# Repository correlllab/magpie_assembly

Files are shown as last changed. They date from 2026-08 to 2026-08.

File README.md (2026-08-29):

<div align="center">

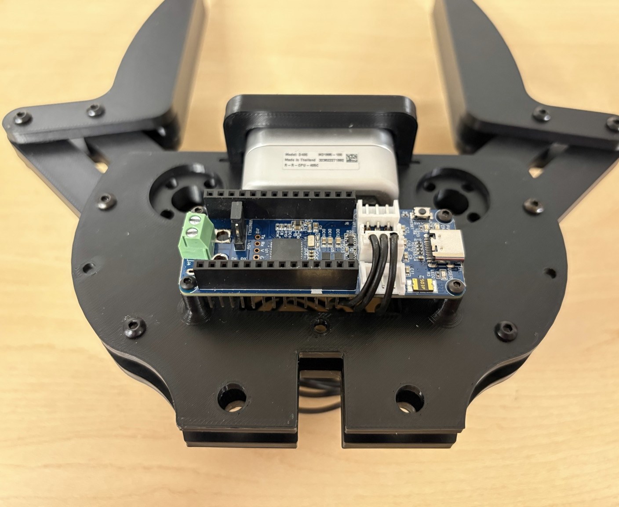
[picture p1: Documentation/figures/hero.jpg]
The assembled Magpie gripper V2, seen from above


# Magpie Gripper

**Design and manufacture of the MAGPIE hand — version 2**

A 3D-printed parallel-jaw gripper with a depth camera in its palm, built from
two smart servos and about $455 of off-the-shelf parts.







</div>

---

Two AX-12A servos drive a four-bar linkage — crank and rocker — that keeps the
fingers parallel through their whole travel, an OpenRB-150 board controls them,
and an Intel RealSense D405 looks out from the palm. Because the servos are
current-limited, the gripper can be told how hard to squeeze; because the camera
is between the fingers rather than on the wrist, it can still see the object at
the moment of contact.

This repository is the **hardware**: models, bill of materials, a photographed
step-by-step build, and the record of what changed from version 1. The software
that drives it lives in [correlllab/MAGPIE](https://github.com/correlllab/MAGPIE).

**Version 2 is a simplification.** Fewer parts, fewer fasteners, and less to get
wrong: the three-piece finger became one piece, the camera moved from slots to
holes so it lands in the same place every time, the controller's standoffs are
printed into the base plate, and the two-piece camera cover became one part that
snaps on. It weighs **390 g** on the bench scale, against 414 g for the hand in
the paper. [What changed, and why →](Documentation/MagpieDesignChanges.md)

|  |  |
| --- | --- |
| **Actuation** | 2 × Dynamixel AX-12A, four-bar linkage per finger |
| **Control** | OpenRB-150, one USB-C cable |
| **Sensing** | Intel RealSense D405 in the palm |
| **Mass** | ≈ 390 g ([weighed](Documentation/assembly_photos/IMG_5022.jpg)) |
| **Parts cost** | ≈ $455, of which the camera is $272 |
| **Printed** | 9 pieces, ≈ 140 cm³, PLA at 30 % gyroid infill |
| **CAD** | Onshape, [live document](https://cad.onshape.com/documents/ebf3bee4cb16cf8695a8fb0b/w/7cb77bbbbc0cfa118c533903/e/7df3b127506ca0a4fec0e6dc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) · STLs in [`CAD/`](CAD) |

## Build one

**1 · Print.** Everything in [`CAD/`](CAD), PLA, 30 % gyroid infill with 2 mm
borders and organic supports. The rocker and the crank are the parts that break,
so give them at least 50 % infill.

<div align="center">
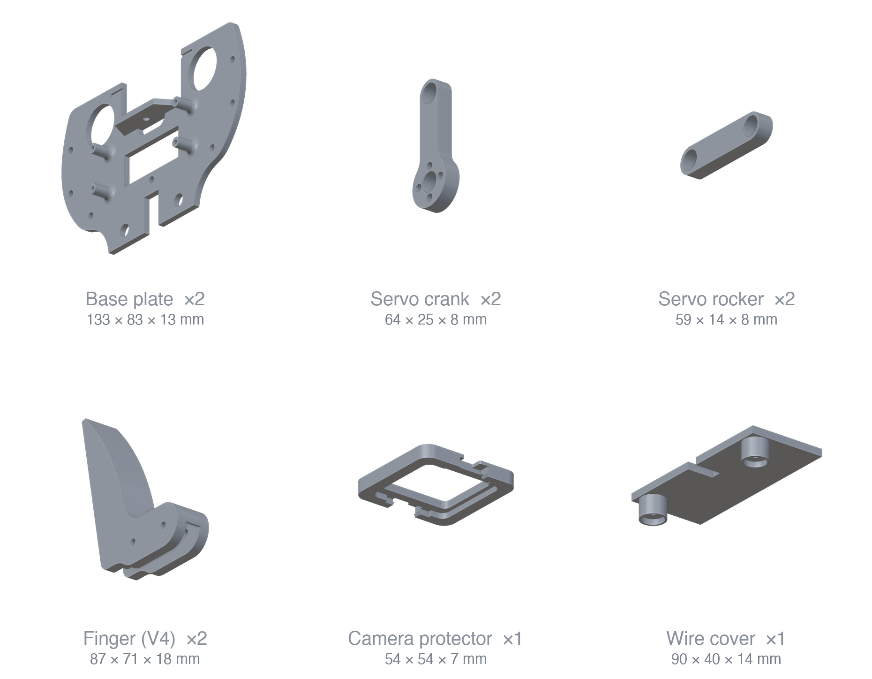
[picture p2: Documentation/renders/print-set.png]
The six printed parts of the V2 gripper, rendered at a common scale

</div>

| | Part | Qty | Size | File |
| --- | --- | ---: | --- | --- |
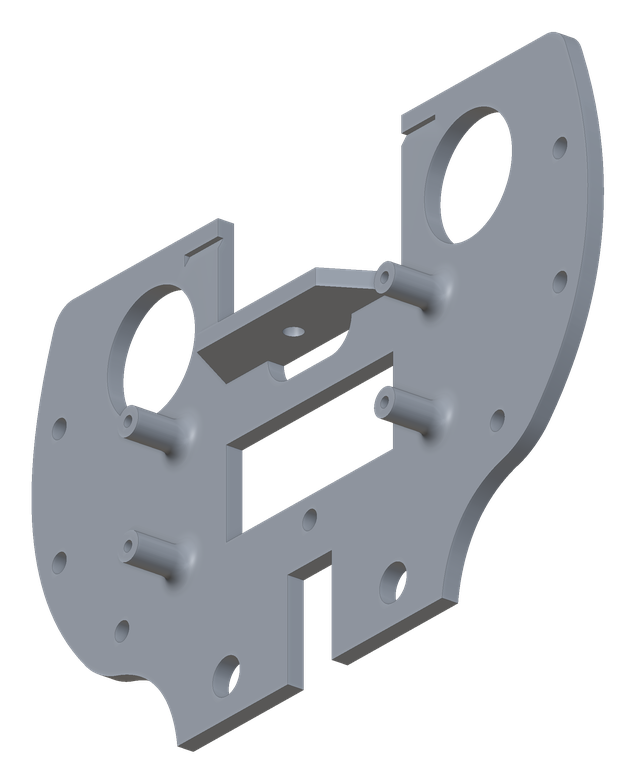
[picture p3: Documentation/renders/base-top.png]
|  | Base plate | 2 | 133 × 83 × 13 mm | [`Base Top.stl`](CAD/Base%20Top.stl), [`Base Bottom.stl`](CAD/Base%20Bottom.stl) |
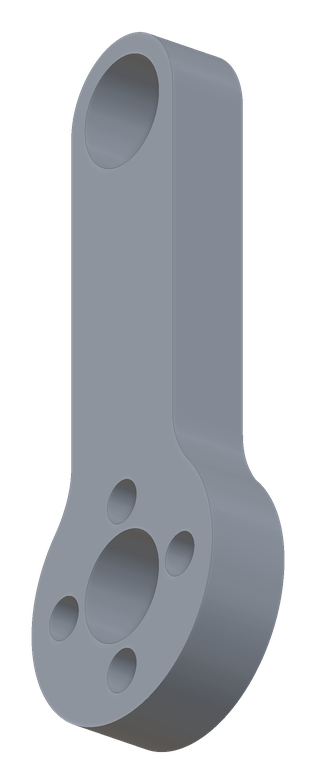
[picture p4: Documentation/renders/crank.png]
|  | Servo crank | 2 | 64 × 25 × 8 mm | [`Crank.stl`](CAD/Crank.stl) |
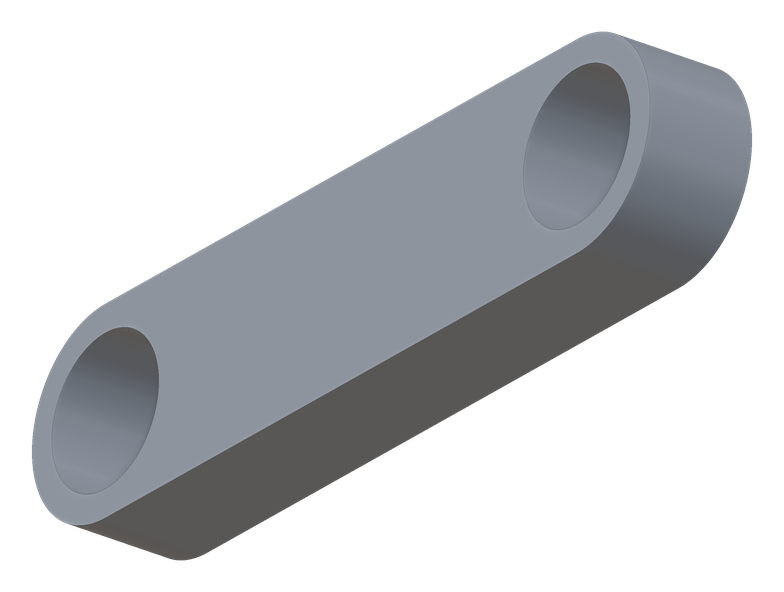
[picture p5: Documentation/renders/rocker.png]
|  | Servo rocker | 2 | 59 × 14 × 8 mm | [`Rocker.stl`](CAD/Rocker.stl) |
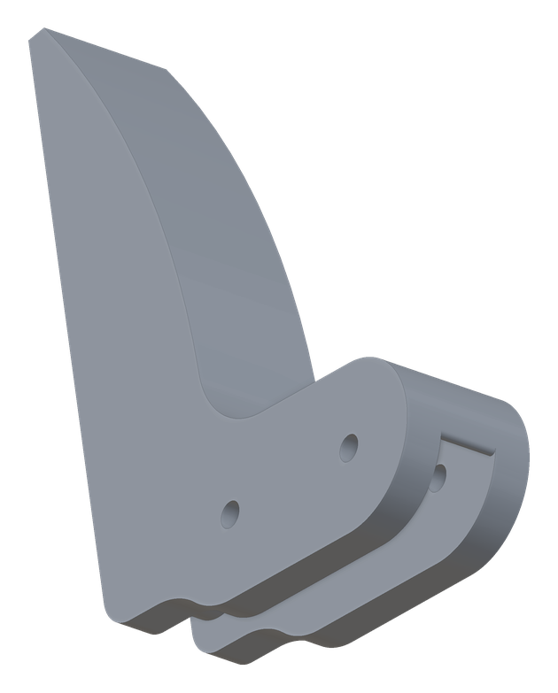
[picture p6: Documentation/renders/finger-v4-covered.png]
|  | Finger | 2 | 87 × 71 × 18 mm | [`Finger V4 - covered.stl`](CAD/Finger%20V4%20-%20covered.stl) |
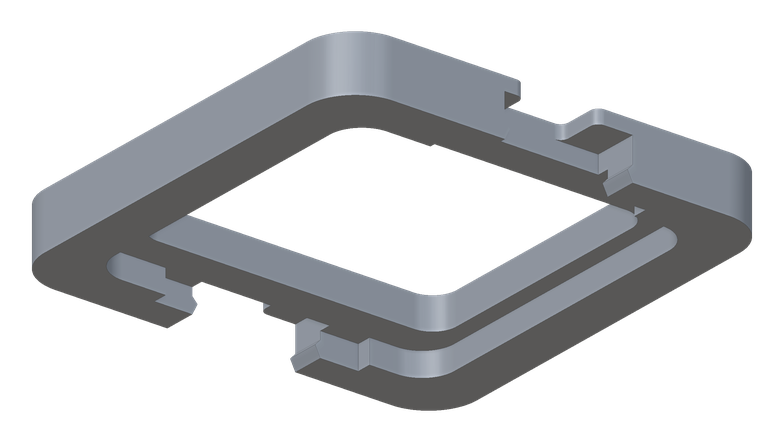
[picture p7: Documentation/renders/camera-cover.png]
|  | Camera protector | 1 | 54 × 54 × 7 mm | [`Camera Cover.stl`](CAD/Camera%20Cover.stl) |
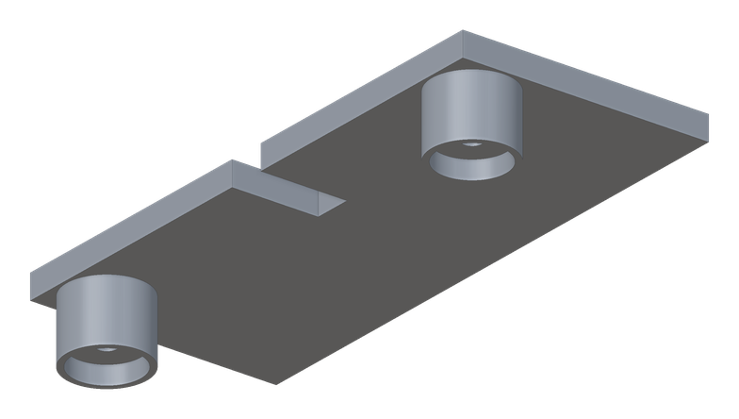
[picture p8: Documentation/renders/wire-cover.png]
|  | Wire cover | 1 | 90 × 40 × 14 mm | [`Wire Cover.stl`](CAD/Wire%20Cover.stl) |

> [!NOTE]
> `Base Top.stl` and `Base Bottom.stl` are currently **the same file, byte for
> byte** — it is the plate carrying the printed OpenRB-150 standoffs. If version 2
> really does use one plate twice, the BOM (which prices them separately) and the
> assembly guide (which says the plates are different sizes) should say so;
> otherwise the second export is missing.

**2 · Buy.** [The bill of materials](Documentation/BOM.md) lists both versions.
For V2: two AX-12A servos, an OpenRB-150, a RealSense D405, six 5 mm bearings,
M2/M3 hardware, and grip tape.

**3 · Assemble.** [The assembly guide](Documentation/assembly.md) — eleven steps,
photographed, from taping the fingers to setting the servo IDs. Also available as
[a PDF to print](Documentation/Magpie%20Assembly%20Guide.pdf).

## The fingers are the experiment

Grip is where a jaw gripper is won or lost, so the finger is the part that has
been through the most versions. All four are in [`CAD/`](CAD) and interchangeable:

<div align="center">
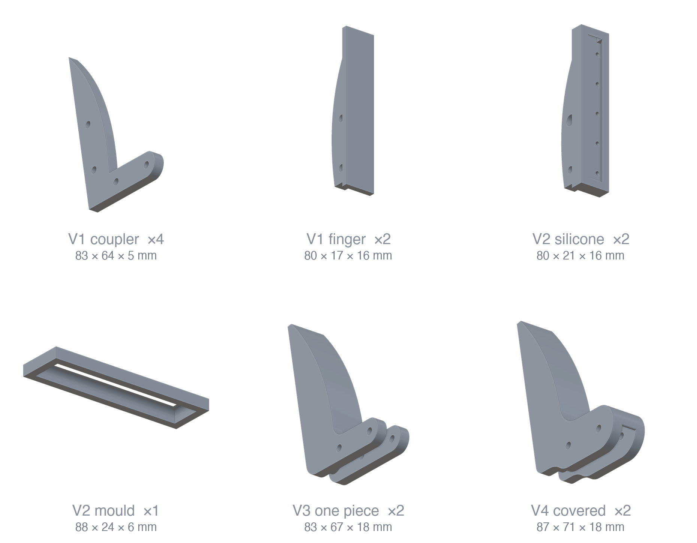
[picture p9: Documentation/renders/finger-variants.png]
The four finger designs rendered side by side

</div>

- **V1** — a separate coupler and finger, so the contact face could be printed in TPU.
- **V2** — a cast silicone finger, with the mould to make it.
- **V3** — finger and coupler as one part; simpler to print and assemble, and it needs grip tape to match the older grip.
- **V4** — V3 plus a cover that takes the play out of the joint and stiffens it.

## Driving it

Force control, the palm camera, grasp planning and the behaviour-tree/PDDL layer
are in **[correlllab/MAGPIE](https://github.com/correlllab/MAGPIE)** — a Python
package, no ROS. Once the gripper is wired and its servo IDs are set, that is
where to go next.

## What is in here

```
CAD/                      STL models — gripper mechanism and every finger variant
Documentation/
  assembly.md             the build, step by step, on GitHub
  Magpie Assembly Guide.pdf   the same guide, to print
  BOM.md                  bill of materials, V1 and V2
  MagpieDesignChanges.md  what changed from V1, and why
  figures/                the guide's figures
  assembly_photos/        every build photo, full resolution
  design_photos/          CAD comparisons, old against new
  renders/                part renders, generated from the STLs
  paper/                  the paper this hand comes from
tools/                    regenerate the renders and the figures
```

## License

MIT — see [LICENSE](LICENSE). The models, the bill of materials and the guide are
yours to print, modify and sell; the software that drives the gripper,
[correlllab/MAGPIE](https://github.com/correlllab/MAGPIE), is MIT too.

Built in the [Correll Lab](https://www.colorado.edu/lab/correll/) at the
University of Colorado Boulder.

## Citation

The hand this one descends from — its four-bar linkage, its force
characterisation and the manipulation pipeline built on it — is described in
[**A versatile robotic hand with 3D perception, force sensing for autonomous
manipulation**](https://arxiv.org/abs/2402.06018) (RSS 2024 Workshop on
Perception and Manipulation Challenges for Warehouse Automation, Daejeon, Korea).
A copy is kept here at
[`Documentation/paper/2402.06018-magpie.pdf`](Documentation/paper/2402.06018-magpie.pdf),
recompressed to keep a clone small — [arXiv](https://arxiv.org/abs/2402.06018) has
the original.

```bibtex
@inproceedings{correll2024versatile,
  title     = {A versatile robotic hand with {3D} perception, force sensing for
               autonomous manipulation},
  author    = {Correll, Nikolaus and Kriegman, Dylan and Otto, Stephen and
               Watson, James},
  booktitle = {RSS Workshop on Perception and Manipulation Challenges for
               Warehouse Automation},
  address   = {Daejeon, Korea},
  year      = {2024},
  eprint    = {2402.06018},
  archivePrefix = {arXiv},
  primaryClass  = {cs.RO},
  url       = {https://arxiv.org/abs/2402.06018}
}
```

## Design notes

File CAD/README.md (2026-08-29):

Updated: 8/19/2026

This directory contains the 3D models for the Magpie Gripper and its interchangeable fingers.

The original parametric modeling for this project was done in Onshape. To ensure compatibility for anyone looking to manufacture or modify the design, the files here have been exported into standard universal formats.

File Format:'.stl': 

Printing Guidelines:
Print using PLA with 30% gyroid infill or 100% infill

Original CAD files are contained within this folder. The CAD assembly is located in this [Onshape](https://cad.onshape.com/documents/ebf3bee4cb16cf8695a8fb0b/w/7cb77bbbbc0cfa118c533903/e/7df3b127506ca0a4fec0e6dc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) document

Renders of every part, generated from these files, are in
[`../Documentation/renders/`](../Documentation/renders); the print set and the
finger variants are laid out side by side there at a common scale.

Note: `Base Top.stl` and `Base Bottom.stl` are currently identical files — the
plate with the printed OpenRB-150 standoffs. See the note in the
[top-level README](../README.md#build-one).

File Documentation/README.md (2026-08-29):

# Documentation

Everything needed to source the parts and put a Magpie gripper together.

| | |
| --- | --- |
| [**assembly.md**](assembly.md) | The step-by-step build, with photographs. Read this on GitHub. |
| [**Magpie Assembly Guide.pdf**](Magpie%20Assembly%20Guide.pdf) | The same guide, formatted to print and take to the bench. |
| [**BOM.md**](BOM.md) | Bill of materials for both versions — hardware, electronics, and grams of filament, with prices. |
| [**MagpieDesignChanges.md**](MagpieDesignChanges.md) | What changed between version 1 and version 2, and the reasoning behind each change. |
| [`figures/`](figures) | The figures used by the assembly guide, cut out of the PDF. |
| [`assembly_photos/`](assembly_photos) | Every photograph taken during the build, full resolution — including the ones the guide did not use. |
| [`design_photos/`](design_photos) | CAD screenshots comparing the old design with the new one. |
| [`renders/`](renders) | Renders of each printed part, generated from the STLs by [`tools/render_stl.py`](../tools/render_stl.py). |
| [`paper/`](paper) | The paper the original hand was published in. |

**If you are building from scratch, read the BOM first** and make sure every item
is on the bench before you start — the guide assumes it.

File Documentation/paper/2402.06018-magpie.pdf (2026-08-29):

# A versatile robotic hand with 3D perception, force sensing for autonomous manipulation

Nikolaus Correll, Dylan Kriegman, Stephen Otto and James Watson Department of Computer Science, University of Colorado Boulder, Boulder, Colorado 80309–0430 Email: ncorrell@colorado.edu

Abstract—We describe a force-controlled robotic gripper with built-in tactile and 3D perception. We also describe a complete autonomous manipulation pipeline consisting of object detection, segmentation, point cloud processing, force-controlled manipulation, and symbolic (re)-planning. The design emphasizes versatility in terms of applications, manufacturability, use of commercial off-the-shelf parts, and open-source software. We validate the design by characterizing force control (achieving up to 32N, controllable in steps of 0.08N), force measurement, and two manipulation demonstrations: assembly of the Siemens gear assembly problem, and a sensor-based stacking task requiring replanning. These demonstrate robust execution of long sequences of sensor-based manipulation tasks, which makes the resulting platform a solid foundation for researchers in task-andmotion planning, educators, and quick prototyping of household, industrial and warehouse automation tasks.

I. INTRODUCTION

Autonomous manipulation remains a challenge in digitizing and automating value streams from manufacturing to recycling. These tasks include picking, placing, assembly/disassembly, and packing. They involve a large variety of compliance, for example when tightening a metal nut vs. grasping a delicate raspberry. Often, tasks of varying dexterity and compliance need to be combined, requiring a highly versatile hardware and software system. Implementing such a system is difficult. Commercially available grippers have limited capabilities, particularly the absence of torque control, and therefore lack of active compliance [1]. Integration with vision systems is not straightforward; wrist-mounted, tabletop, and palm-mounted cameras can be occluded at different times during operation. Finally, software frameworks such as ROS take considerable effort to commission and maintain, which is often unnecessary in particular when the goal is to investigate only one aspect of a manipulation pipeline such as vision or high-level reasoning. In this paper, we present a lightweight manipulation architecture geared at researchers, educators, and hobbyists, that is able to perform a wide variety of multi-step manipulation tasks, while being simple to manufacture and affordable (Figure 1).
The “gold standard” in manipulation is the human hand, which is able to perform an extensive range of tasks, including tool usage and in-hand manipulation [13]. Prominent designs in this category are the “ShadowHand” that is able to manipulate a Rubik’s cube [2], the RBO hand [4], and the Pisa/IIT hand [7]. These three examples also span a large spectrum of degrees of freedom from 24 (ShadowHand) to

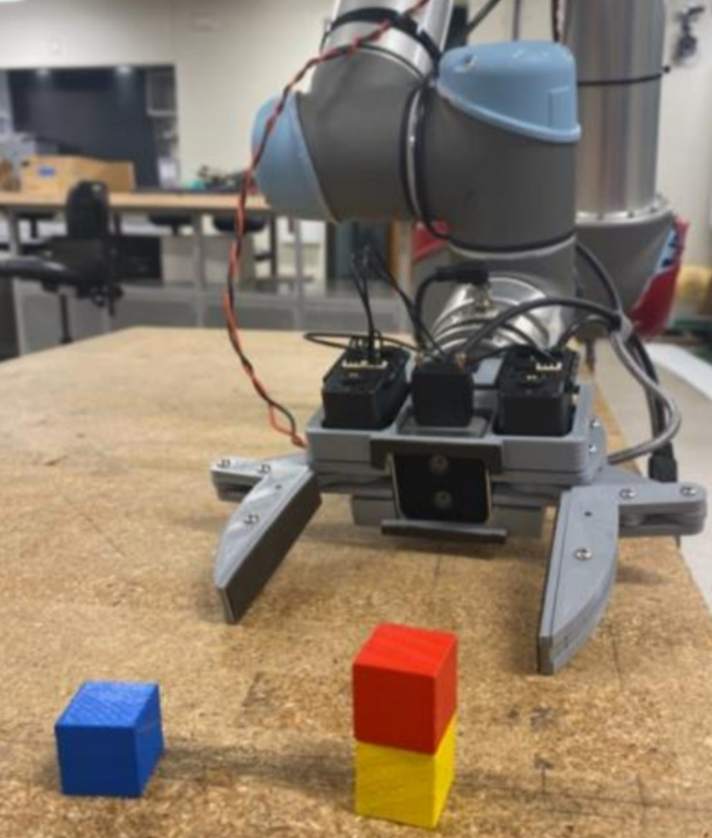
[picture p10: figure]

Fig. 1. All-in-one manipulation architecture that emphasizes manufacturability, active compliance, robust execution, and versatility. A light-weight software architecture combines object detection, segmentation, point cloud processing, with planning, inference and execution, creating a platform for research in task-and-motion planning for complex manipulation problems.
the underactuated Pisa hand which has 19 joints driven by only a single actuator. Benchmarking an end-effector design is a challenging problem and subject to research. It is difficult to disentangle grasp planning from perception [3], robot arm from end-effector performance [19], and versatility from specialization, e.g. cloth manipulation [16] or warehouse picking [10].
One way to evaluate the capability of a hand design is to subject it to a wide variety of household tasks [22] that overlap with upper-limb prosthetic applications. In such a test, underactuated designs such as the Pisa hand [5] and a 100-year old claw design that has only a single actuated finger
[20] have outperformed all other designs in [22]. Although the Pisa hand’s compliance is advantageous when operating scissors, e.g., a simple mechanical design is intriguing due to its manufacturability, robustness, and simpler control [14] while still being highly versatile.
Although versatility is not important in conventional automation using highly specialized end-effectors such as during warehouse picking or assembly of the same part, versatility

# arXiv:2402.06018v1 [cs.RO] 8 Feb 2024

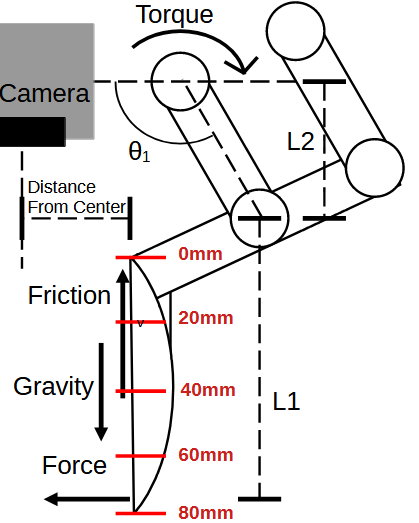
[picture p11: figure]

Fig. 2. Torque Diagram to Calculate Estimated Force on the Object.
will become critical for recovering from errors or when a task not only requires picking, but precise placement, e.g. during packing.
In previous work, we have designed an industrial-grade robotic gripper following these design principles that integrated 3D perception, force control and computation [12] to pick up items as small as a washer and as large as a commercial toner cartridge. The system is gentle enough to handle a strawberry, and strong enough to tighten a nut. In this paper, we describe a design with much-improved manufacturability by relying on commercial, off-the-shelf motors and cameras, forgoing costly custom integration of computation and cabling. Although sacrificing ruggedness and stand-alone capability, this design can be manufactured at a fraction of the cost (around $460 in parts including camera), and less than half of the weight (414g), allowing operation on a wide range of robotic arms, while requiring only a 3D printer and off-theshelf parts such as stand-offs and bearings.
Based on experience with a wide range of robotic competitions ranging from warehouse picking [10], household automation [20], robotic assembly [24] and mobile manipulation [21], we have developed a perception and planning pipeline that combines recent advances in low-cost 3D perception with deep learning for instance-segmentation, and conventional planning. Here, the emphasis of our architecture is to robustly deal with sequencing hundreds of behaviors based on visual and tactile cues. The software stack is released under the MIT License¹ .

II. DESIGN

A. Hardware
Our design is driven by the requirement to perform assembly tasks involving parts as small as M3 nuts driven by the robotic assembly domain [24] and household tasks as in [22]. Trading strength and size for manufacturability and cost, we designed the system to pick up 88% of the items in the YCB benchmark [6], excluding the hammer, the power drill, the pan, and other large objects. With this, we were able to specify the gripper aperture and motor strength, assuming a conservative friction coefficient of µ = 0.4 and a safety factor of 1.5.

1https://github.com/correlllab/MAGPIE

The 4-bar linkage design (Figure 2) provides a maximal field of view for the palm-mounted camera (Intel RealSense D405), providing a maximum aperture of w = 106.24mm. All pieces have been 3D printed using PLA. Although PLA printed parts have lesser stiffness than Delrin or ABS sheets, laser cutters are not available to most educators and hobbyists. All links use M5 bearings that are press-fitted into openings in the PLA material and M3 screws as the axis. We found using bearings to greatly reduce friction, while press-fitting reduces play and thereby increases the accuracy of the mechanism. The AX-12 servo motors (Robotis, Korea) have a stalltorque τ of 1.5Nm. The AX-12’s digital interface allows setting and measuring the actual motor torque via current control, thereby enabling compliant control and detecting objects within the gripper. Independently controlling the fingers helps to prevent the gripper to get stuck when one of its fingers is impeded, e.g. when picking items from clutter, as well as grasping objects off center [12].
The Intel RealSense camera has an operational range from 7cm to 50cm with a field of view of 87o × 58o

and a resolution
of 1280 × 720. It can detect objects as small as 0.1mm, making it ideal for in-hand perception applications. The camera is mounted in the palm [12], allowing the hand to see an object until contact is made, minimizing distortion and occlusion, when compared to wrist- and table-mounted cameras. Figure 6 (center), shows a snapshot through the camera, with only minimal occlusion by the fingers.
B. Software
Our grasping pipeline follows the outline described in [11]: objects are detected from RGB camera images using pixelwise segmentation based on Yolo v5²
. Segmentation masks
are then used to isolate 3D point cloud information from individual objects. We determine the orientation of the point cloud using principal component analysis (PCA), compute a grasp pose based on the object’s bounding box, and use an inverse kinematics solver from Peter Corke’s robotic toolbox
[9] to move the robotic arm to the desired pose. Together, these components create a robust pipeline in which individual elements can be replaced for research or education. All of the behaviors are embedded into Behavior Tree (BT) [8] nodes that allow for robust engineering of multi-state robot controllers.
In order to be able to manage long task sequences comprising hundreds of steps, e.g. as required during assembly of complex mechatronics [24], our planner automatically generates BTs from a high-level task description of the scene in PDDL 2.1 [15], which can be efficiently solved by the AI planning framework FastDownward [17] that we interface via py2PDDL [18]. Here, the planning problem is populated from the Yolo v5 object recognition pipeline after every step and the plan is recomputed to catch potential execution failures. Here, spatial relationships between objects (e.g. “on top”) are hard-coded. This framework is illustrated in Figure 6, showing

2https://github.com/ultralytics/yolov5

Bill of Materials

ID | Item | Quantity | Cost
1 | Top Base(PLA) | 1 | $ 1.51
2 | Top Base Cover(PLA) | 1 | $ 2.05
3 | Bottom Base(PLA) | 1 | $ 1.17
4 | Bottom Base Cover(PLA) | 1 | $ 1.15
5 | Servo Crank(PLA) | 2 | $ 0.47
6 | Servo Coupler(PLA) | 4 | $ 1.56
7 | Servo Rocker(PLA) | 2 | $ 0.28
8 | Finger | 2 | $ 0.86
9 | OpenRB-150 board | 1 | $ 24.90
10 | Intel® RealSense™ D405 | 1 | $ 272.00
11 | AX-12A Servo Motor | 2 | $ 99.80
12 | 3M 6mm standoff | 4 | $ 9.99
13 | 3M 8mm standoff | 8 | $ 9.99
14 | 2.5M 10mm standoff | 4 | $ 9.99
15 | Electrical Wire | 2 | $ 0.45
16 | 3M Nuts and Bolts | 32 | $ 12.49
17 | 2M Nuts and Bolts | 8 | $ 9.99
18 | 5M bearings | 8 | $ 9.99
| | Total | $458.63

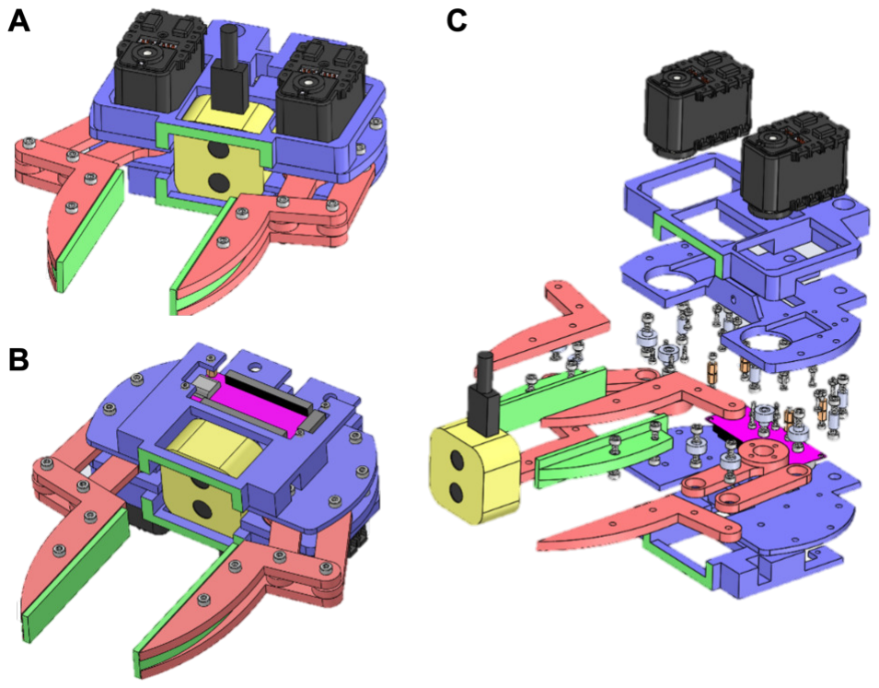
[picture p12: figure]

Fig. 3. | Left: CAD Drawings of the gripper from the top (A), bottom (B), and exploded view (C). Each motor independently actuates a finger, providing
independent torque-based control. The camera is integrated into the palm. Right: Bill of Materials with approximated cost. PLA with a cost of $0.05 per cm2 .

an example of successful task completion despite errors during
execution by continuous replanning.

III. EVALUATION
a) Hardware: In order to test the torque-controlling ability of the servo, we measure the force at the finger as a function of the dimensionless Dynamixel settings in the range of 0–1023. A force gauge (Shimpo FGV-10XY) was locked into a vice to hold it securely for all measurements. The force gauge gives an error of ±.2%. The force increases linearly (R² = .995, y = 0.0316x−3.0194) from 0 to 9N at “400” and then increases to 32N following a second-degree polynomial function (R² = .999). In the linear regime, we are able to change force in increments of 0.08N.
We also demonstrate the gripper’s ability to sense force/torque. Figure 4 shows the force profile for the right (‘Motor 1’) and the left (‘Motor 2’) finger vs. gripper aperture as the gripper closes on the mustard container from the YCB dataset. The container was placed off-center, with the right motor making contact first. Instead of moving the mustard, the finger remains in position until the second finger makes contact. We observe minimal torques while moving the finger, with Motor 1 having more friction than Motor 2 due to variations in manufacturing.
To demonstrate the precision and accuracy of the design, we perform a robotic assembly task with tight tolerances (< 0.5mm). Snapshots of the task are shown in Figure 5. Precision and accuracy of grasping the elements from a known position on the kitting mat (modeling the industrial assembly challenge requirements from [24]) is sufficient to reliably assemble all parts into a functioning mechanical system. The open-loop assembly task succeeded 8 out of 10 trials; with one failure each due to an angular misalignment of the small peg and the large gear becoming jammed on the large peg. These results motivate a sensor-based re-planning approach such as described in [25].
b) Software: We evaluated the system using a towerassembly task using three colored, wooden cubes from [6].

Figure 6 shows snapshots of the experiment, a view of the camera image, the resulting labeled 3D objects, and the corresponding PDDL domain. FastDownward automatically generates a plan, which our system translates into a behavior tree to execute the necessary steps. Running this loop once corresponds to the classical sense-plan-act approach. Updating the PDDL domain and replanning accordingly allows for more sophisticated behavior, including reacting to changes in the environment or recovering from errors in execution. We ran a single step, moving one block from one tower to another, 50 times. Of the 42 successful attempts, 30 were completed at the first trial, 6 required two trials, and 3, 2, and 1 experiments required 3, 4, and 6 trials. The other 8 failed in a way that could not be recovered with this simple program, for example when a block was moved out of the field of view of the hand.

IV. DISCUSSION AND CONCLUSION
The proposed design exceeds the capabilities of [12] in terms of perception and in the dimensions of objects that can be picked up. Yet, 3D-printed PLA plastics cannot reach the level of stiffness and accuracy that a sheet-metal-based design can, which is a disadvantage when grasping very small pieces, such as an M3 screw that requires exact alignment of the fingers.
The current design requires three external cables that need to be routed along a robotic arm: a USB 3.1 connection for the camera, a USB 2.0 connection for the motor control board, and a power cable that can provide up to 3A at 12V (36W). All of these could be met by a single USB-C PD connection, in particular when 5V to 12V step-up circuits with sufficient power are available.
The emphasis on the software pipeline is to demonstrate modularity (via the BT framework and STRIPS planner), rather than performance on specific subtasks. Indeed, components such as object detection could be easily tuned to achieve 100% one-shot success rate in the tower assembly task. Failure has been instructive as it will be pervasive in autonomous settings, and remain a problem if it occurs with a non-zero

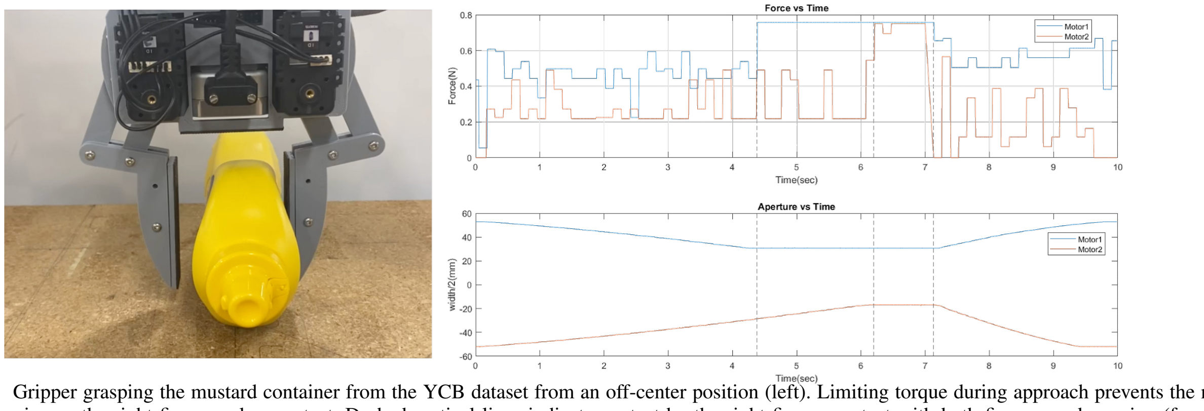
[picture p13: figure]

Fig. 4. Gripper grasping the mustard container from the YCB dataset from an off-center position (left). Limiting torque during approach prevents the mustard from moving as the right finger makes contact. Dashed vertical lines indicate contact by the right finger, contact with both fingers, and opening (from left to right).

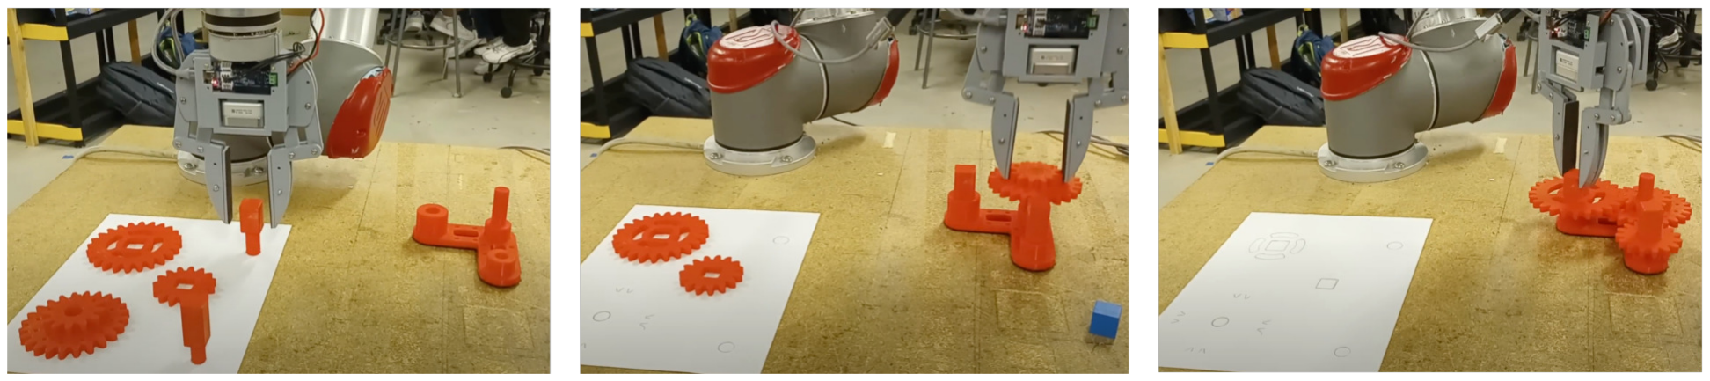
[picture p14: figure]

Fig. 5. Demonstration of accuracy and precision by reliably assembling the “Siemens gear assembly problem” [23] with sub-millimeter accuracy requirements.

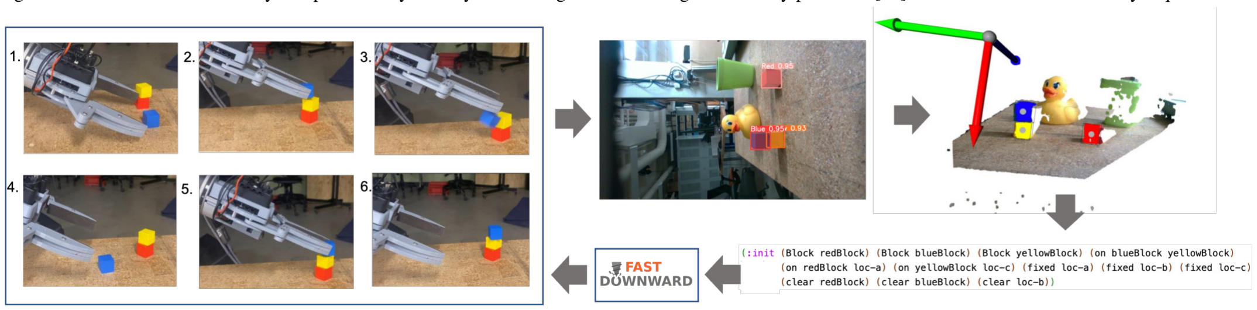
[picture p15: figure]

Fig. 6. Snapshots from a tower construction task that is solved by continuous replanning. The robot accidentally hits the tower (1) while placing the blue block (2), which fails as the tower has moved (3), the robot re-analyzes the scene (4), and places the blue block (5). Point cloud and image data are used for object identification and segmentation, resulting into a labeled scene that gets parsed into a PDDL 2.1 problem description and solved by FastDownward. The plan is repeated until the problem is solved.

probability. Here, we are particularly interested in reasoning
under uncertainty and generating high-level plans for recovery
from error using semantic domain knowledge. For example, when an object moves outside of the robot’s field of view, the robot could search for it and move objects out of the way if it has to. We plan to further explore this in the future by interfacing PDDL descriptions with large language models to (1) generate problem descriptions from image/3D data,
(2) generate PDDL descriptions from natural language, and
(3) use domain knowledge to increase the robot’s reasoning abilities. Finally, we are interested in building upon this design to perform better on heavy items by adding a thumb, operating tools such as a power-drill by adding an additional degree of freedom to one finger, and fast picking by adding a suction

cup.

ACKNOWLEDGEMENTS
This work has been supported by a grant by the National Science Foundation “USDA-NIFA NRI INT: Autonomous Restoration and Revegetation of Degraded Ecosystems”.

REFERENCES
[1] A. Albu-Schaffer, O. Eiberger, M. Grebenstein, S. Haddadin, C. Ott, T. Wimbock, S. Wolf, and G. Hirzinger. Soft robotics. IEEE Robotics & Automation Magazine, 15(3):20–30, 2008.
[2] O. M. Andrychowicz, B. Baker, M. Chociej, R. Jozefowicz, B. McGrew, J. Pachocki, A. Petron, M. Plappert,
G. Powell, A. Ray, et al. Learning dexterous in-hand manipulation. The International Journal of Robotics Research, 39(1):3–20, 2020.
[3] Y. Bekiroglu, N. Marturi, M. A. Roa, K. J. M. Adjigble,
T. Pardi, C. Grimm, R. Balasubramanian, K. Hang, and
R. Stolkin. Benchmarking protocol for grasp planning algorithms. IEEE Robotics and Automation Letters, 5 (2):315–322, 2019.
[4] A. Bhatt, A. Sieler, S. Puhlmann, and O. Brock. Surprisingly robust in-hand manipulation: An empirical study. arXiv preprint arXiv:2201.11503, 2022.
[5] M. Bonilla, C. D. Santina, A. Rocchi, E. Luberto, G. Santaera, E. Farnioli, C. Piazza, F. Bonomo, A. Brando,
A. Raugi, et al. Advanced grasping with the pisa/iit softhand. In Robotic Grasping and Manipulation: First Robotic Grasping and Manipulation Challenge, RGMC 2016, Held in Conjunction with IROS 2016, Daejeon, South Korea, October 10–12, 2016, Revised Papers 1, pages 19–38. Springer, 2018.
[6] B. Calli, A. Singh, J. Bruce, A. Walsman, K. Konolige,
S. Srinivasa, P. Abbeel, and A. M. Dollar. Yale-cmuberkeley dataset for robotic manipulation research. The International Journal of Robotics Research, 36(3):261– 268, 2017.
[7] M. G. Catalano, G. Grioli, E. Farnioli, A. Serio, C. Piazza, and A. Bicchi. Adaptive synergies for the design and control of the pisa/iit softhand. The International Journal of Robotics Research, 33(5):768–782, 2014.
[8] M. Colledanchise and P. Ogren. ¨ | Behavior trees in
robotics and AI: An introduction. CRC Press, 2018.
[9] P. Corke and J. Haviland. Not your grandmother’s toolbox–the robotics toolbox reinvented for python. In 2021 IEEE International Conference on Robotics and Automation (ICRA), pages 11357–11363. IEEE, 2021.
[10] N. Correll, K. E. Bekris, D. Berenson, O. Brock,
A. Causo, K. Hauser, K. Okada, A. Rodriguez, J. M. Romano, and P. R. Wurman. Analysis and observations from the first amazon picking challenge. IEEE Transactions on Automation Science and Engineering, 15(1): 172–188, 2016.
[11] N. Correll, B. Hayes, C. Heckman, and A. Roncone. Introduction to Autonomous Robots: Mechanisms, Sensors, Actuators, and Algorithms. Mit Press, 2022.
[12] N. J. Correll, A. K. Miller, and B. Romero. Systems, devices, components, and methods for a compact robotic gripper with palm-mounted sensing, grasping, and computing devices and components, Oct. 19 2021. US Patent 11,148,295.
[13] R. Coulson, C. Li, C. Majidi, and N. S. Pollard. The elliott and connolly benchmark: A test for evaluating the in-hand dexterity of robot hands. In 2020 IEEE-RAS 20th International Conference on Humanoid Robots (Humanoids), pages 238–245. IEEE, 2021.
[14] R. S. Fearing. Simplified grasping and manipulation with dextrous robot hands. IEEE Journal on Robotics and Automation, 2(4):188–195, 1986.
[15] M. Fox and D. Long. Pddl2.1: An extension to pddl for expressing temporal planning domains. Journal of artificial intelligence research, 20:61–124, 2003.
[16] I. Garcia-Camacho, M. Lippi, M. C. Welle, H. Yin,
R. Antonova, A. Varava, J. Borras, C. Torras, A. Marino,
G. Alenya, et al. Benchmarking bimanual cloth manipulation. IEEE Robotics and Automation Letters, 5(2): 1111–1118, 2020.
[17] M. Helmert. The fast downward planning system. Journal of Artificial Intelligence Research, 26:191–246, 2006.
[18] R. Karem. | py2pddl. | https://github.com/remykarem/
py2pddl, (https://github.com/remykarem/py2pddl) 2022.
[19] A. S. Morgan, K. Hang, W. G. Bircher, F. M. Alladkani,
A. Gandhi, B. Calli, and A. M. Dollar. Benchmarking cluttered robot pick-and-place manipulation with the box and blocks test. IEEE Robotics and Automation Letters, 5(2):454–461, 2019.
[20] R. Patel, J. Segil, and N. Correll. Manipulation using the “utah” prosthetic hand: The role of stiffness in manipulation. In Robotic Grasping and Manipulation: First Robotic Grasping and Manipulation Challenge, RGMC 2016, Held in Conjunction with IROS 2016, Daejeon, South Korea, October 10–12, 2016, Revised Papers 1, pages 107–116. Springer, 2018.
[21] M. A. Roa, M. R. Dogar, J. Pages, C. Vivas,
A. Morales, N. Correll, M. Gorner, J. Rosell, S. Foix,
R. Memmesheimer, et al. Mobile manipulation hackathon: Moving into real world applications. IEEE Robotics & Automation Magazine, 28(2):112–124, 2021.
[22] Y. Sun, J. Falco, N. Cheng, H. R. Choi, E. D. Engeberg,
N. Pollard, M. Roa, and Z. Xia. Robotic grasping and manipulation competition: task pool. In Robotic Grasping and Manipulation: First Robotic Grasping and Manipulation Challenge, RGMC 2016, Held in Conjunction with IROS 2016, Daejeon, South Korea, October 10– 12, 2016, Revised Papers 1, pages 1–18. Springer, 2018.
[23] M. Vecerik, O. Sushkov, D. Barker, T. Rothorl, T. Hester, ¨ and J. Scholz. A practical approach to insertion with variable socket position using deep reinforcement learning. In 2019 international conference on robotics and automation (ICRA), pages 754–760. IEEE, 2019.
[24] F. Von Drigalski, C. Schlette, M. Rudorfer, N. Correll,
J. C. Triyonoputro, W. Wan, T. Tsuji, and T. Watanabe. Robots assembling machines: learning from the world robot summit 2018 assembly challenge. Advanced Robotics, 34(7-8):408–421, 2020.
[25] J. Watson, A. Miller, and N. Correll. Autonomous industrial assembly using force, torque, and rgb-d sensing. Advanced Robotics, 34(7-8):546–559, 2020.

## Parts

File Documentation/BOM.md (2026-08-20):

# Magpie Gripper Bill of Materials (BOM)

Note: All parts printed out of PLA are under the assumption that filament costs $0.05 per cm<sup>2

## Version 1

Note: All parts printed out of PLA have 15% crosshatch infill with 2mm borders and organic supports.

| ID | Item | Quantity | Cost (Approx.)
|---|---|---|---|
|1|Top Base (PLA)|1|$1.51|
|2|Top Base Cover (PLA)|1|$2.05|
|3|Bottom Base (PLA)|1|$1.17|
|4|Bottom Base Cover (PLA)|1|$1.15|
|5|Servo Crank (PLA)|2|$0.47|
|6|Servo Coupler (PLA)|4|$1.56|
|7|Servo Rocker (PLA)|2|$0.28|
|8|Finger (PLA)|2|$0.86|
|9|OpenRB-150 board|1|$24.90|
|10|Intel :registered: RealSense :tm: D405|1|$272.00|
|11|AX-12A Servo Motor|2|$99.80|
|12|3M 6mm standoff|4|$9.99|
|13|3M 8mm standoff|8|$9.99|
|14|2.5M 10mm standoff|4|$9.99|
|15|Electrical Wire|2|$0.45|
|16|3M Nuts and Bolts|32|$12.49|
|17|2M Nuts and Bolts|8|$9.99|
|18|5M bearings|8|$9.99|
| | |Total|$468.64|

## Version 2 (New)

Note: All parts printed out of PLA have 30% gyroid infill with 2mm borders and organic supports

| ID | Item | Quantity | Cost (Approx.) | 
|---|---|---|---|
|1|Top Base (PLA)|1|$1.01|
|2|Bottom Base (PLA)|1|$1.20|
|3|Servo Crank (PLA)|2|$0.52|
|4|Servo Rocker (PLA)|2|$0.38|
|5|Finger (PLA)|2|$2.20|
|6|Camera Protector (PLA)|1|$0.36|
|7|OpenRB-150 board|1|$24.90|
|8|Intel :registered: RealSense :tm: D405|1|$272.00|
|9|AX-12A Servo Motor|2|$99.80|
|10|3M 6mm standoff|4|$9.99|
|11|3M 8mm standoff|4|$9.99|
|12|Electrical Wire|2|$0.45|
|13|3M Nuts and Bolts|16|$12.49|
|14|2M Nuts and Bolts|20|$9.99|
|15|5M bearings|6|$9.99|
| | |Total|$455.28|

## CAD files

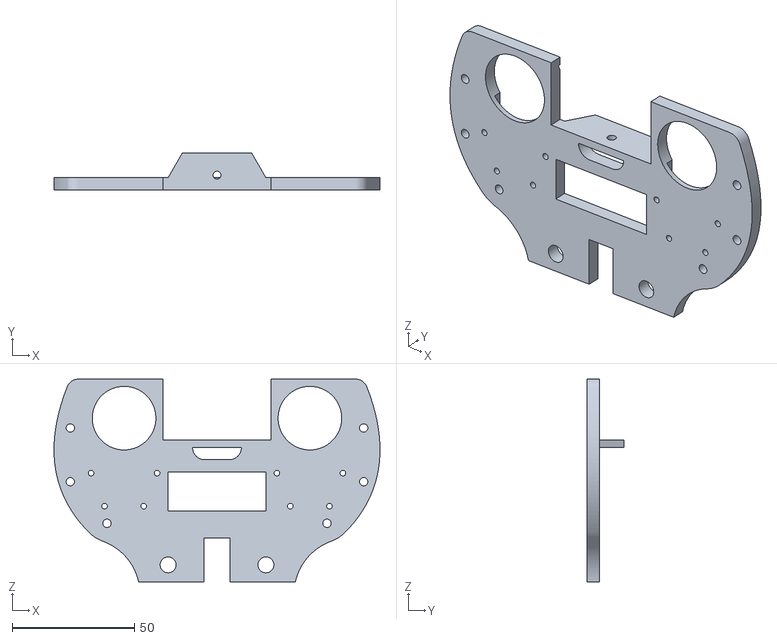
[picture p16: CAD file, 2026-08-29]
CAD/Top Base.stl
133.3 x 15.0 x 83.0

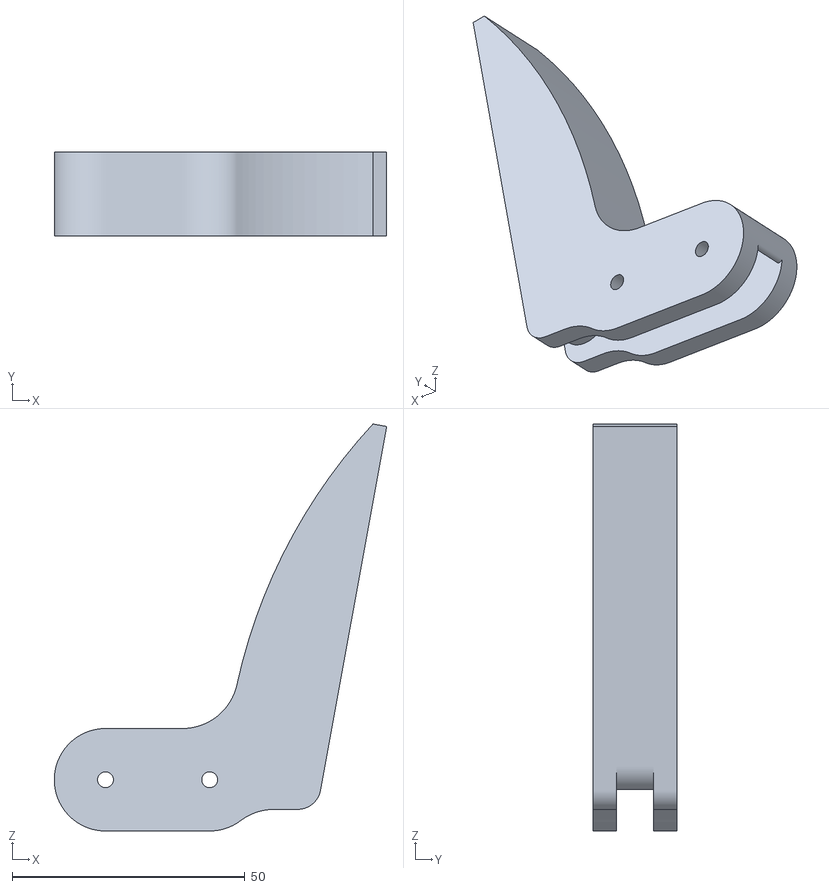
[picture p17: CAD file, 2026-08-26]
CAD/Finger V4 - covered.stl
71.4 x 18.0 x 87.4

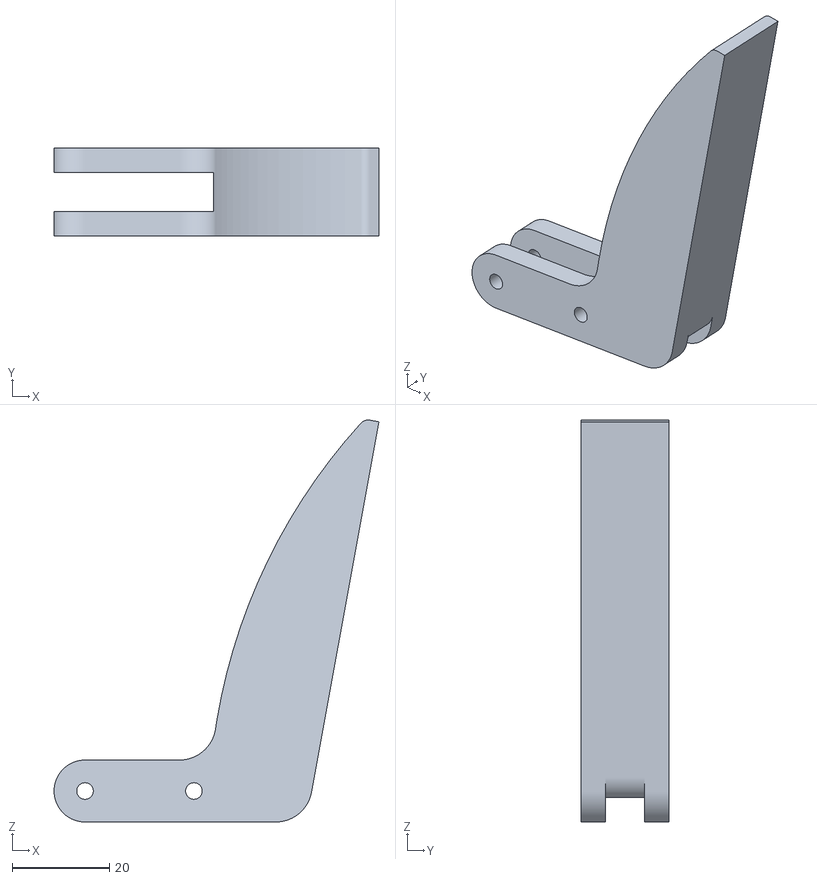
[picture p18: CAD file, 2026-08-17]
CAD/Finger V3 - Finger+Coupler.stl
66.7 x 18.0 x 82.6

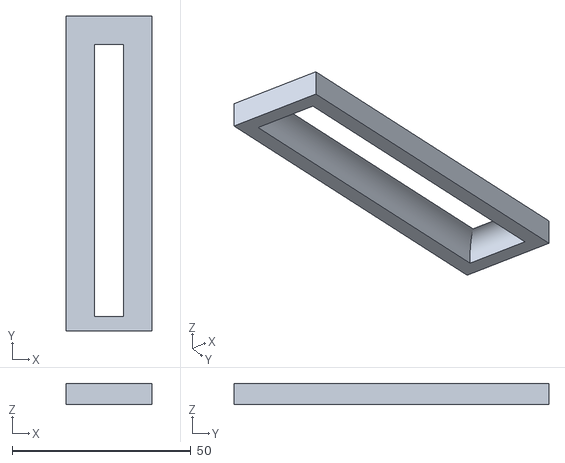
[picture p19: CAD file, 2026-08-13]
CAD/Finger V2 - Silicone Finger Mold.stl
24.2 x 88.2 x 6.00

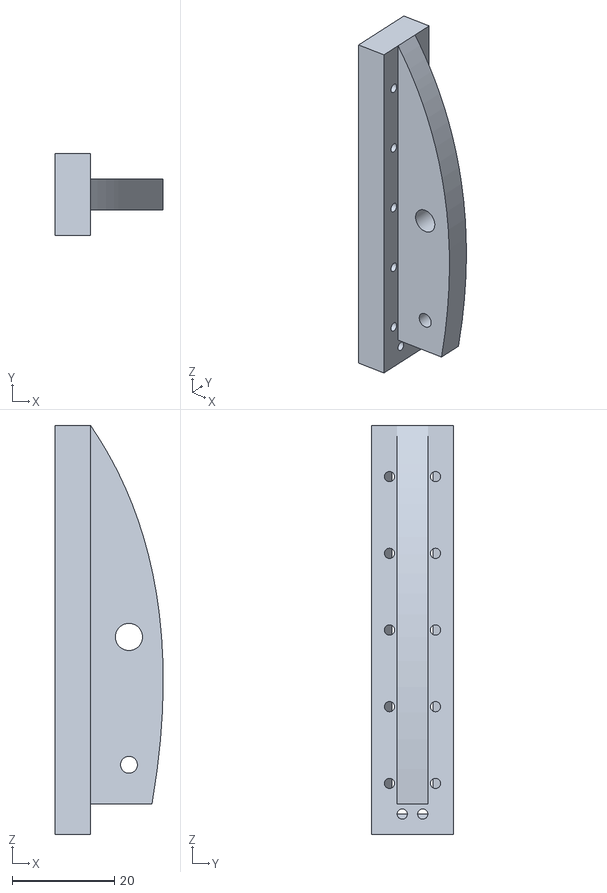
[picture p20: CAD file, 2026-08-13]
CAD/Finger V2 - Silicone Finger.stl
21.2 x 16.0 x 80.0

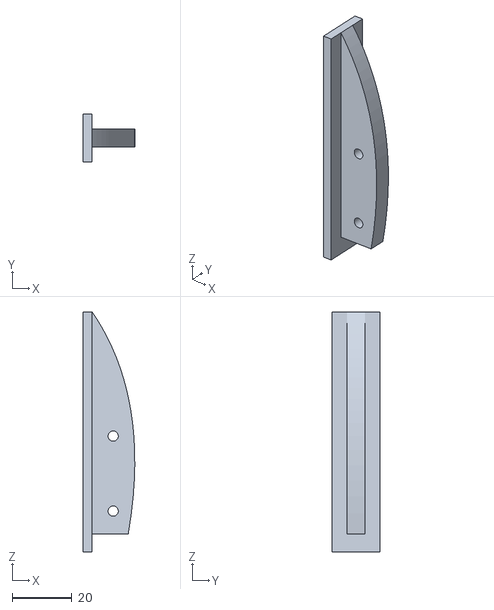
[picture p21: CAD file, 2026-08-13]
CAD/Finger V1 - Finger.stl
17.2 x 16.0 x 80.0

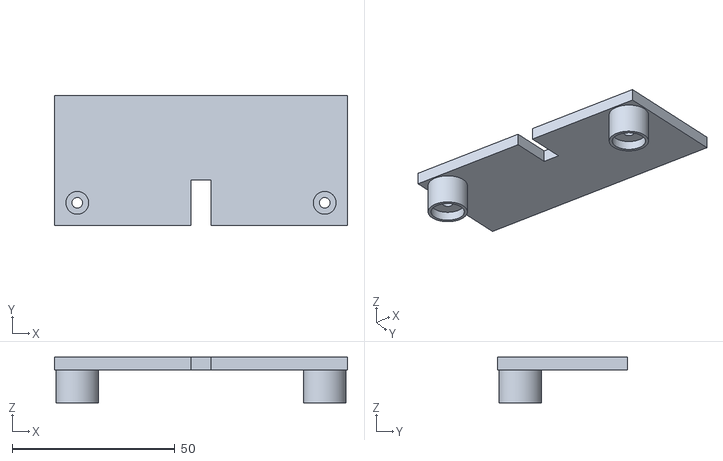
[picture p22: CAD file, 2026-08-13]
CAD/Wire Cover.stl
90.0 x 40.0 x 14.0

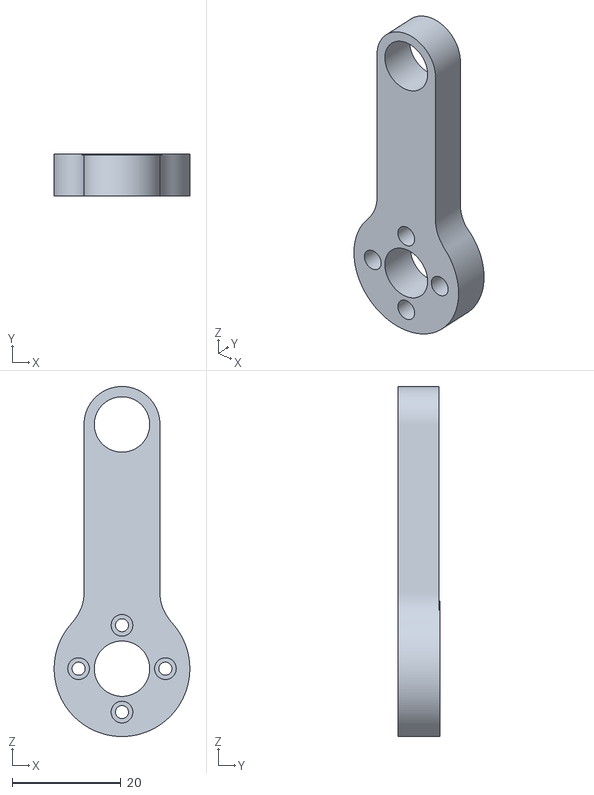
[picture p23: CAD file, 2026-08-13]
CAD/Crank.stl
25.0 x 7.80 x 64.5

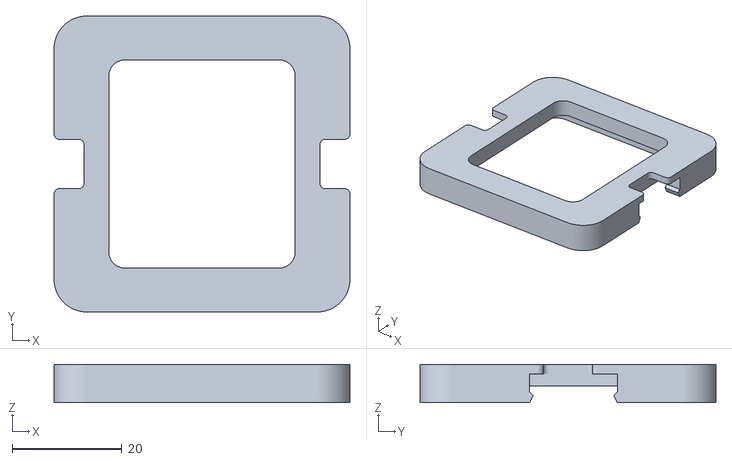
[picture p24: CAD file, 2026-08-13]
CAD/Camera Cover.stl
54.0 x 54.0 x 7.00

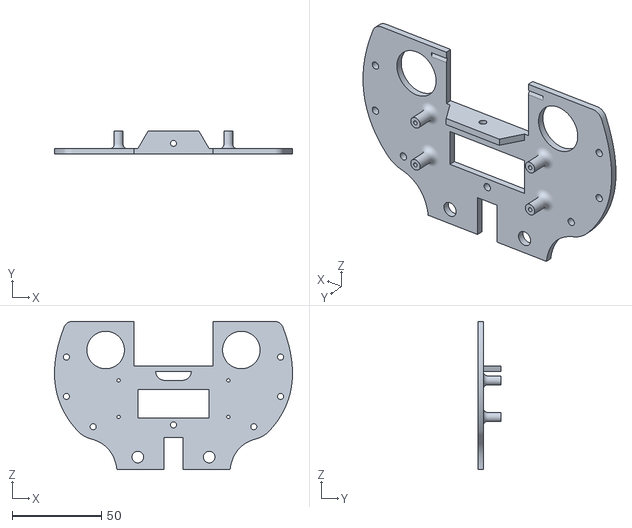
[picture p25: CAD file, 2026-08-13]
CAD/Bottom Base.stl
133.4 x 13.0 x 83.0

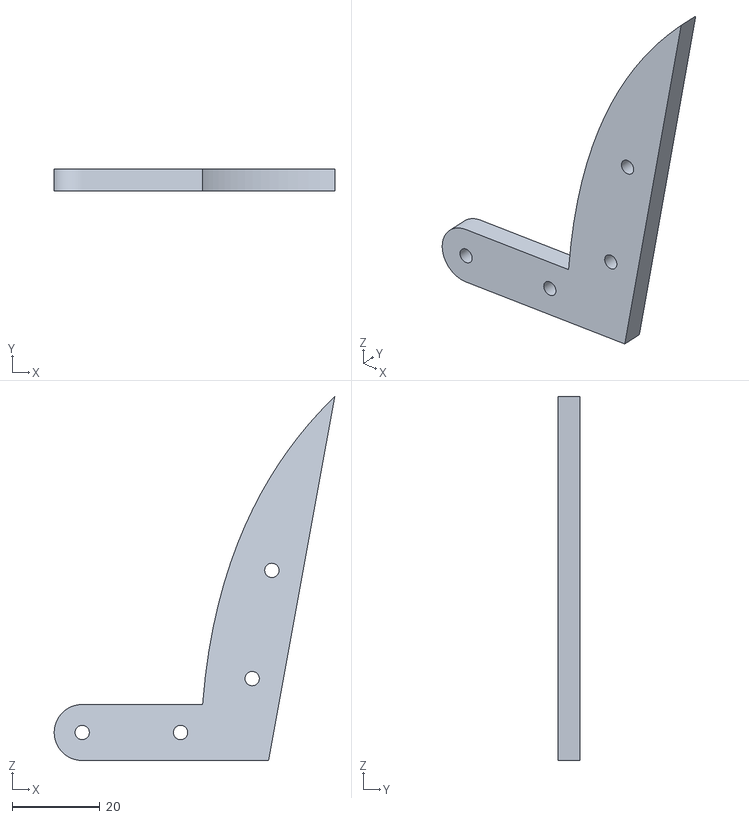
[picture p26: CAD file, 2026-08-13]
CAD/Finger V1 - Coupler.stl
63.8 x 5.00 x 82.7

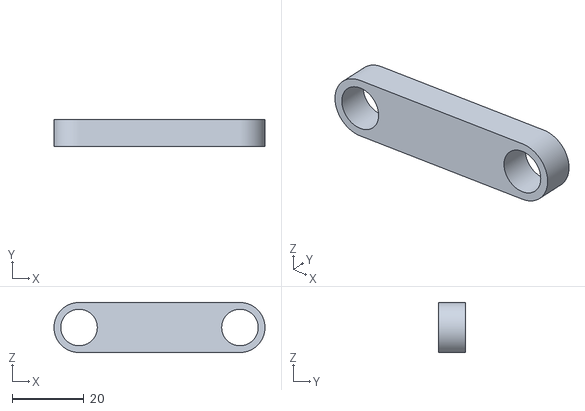
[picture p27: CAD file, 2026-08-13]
CAD/Rocker.stl
59.0 x 7.60 x 14.0

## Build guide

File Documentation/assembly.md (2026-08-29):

# Magpie Gripper V2 — assembly

The same guide as [`Magpie Assembly Guide.pdf`](Magpie%20Assembly%20Guide.pdf), in a
form GitHub renders — no download, and it works on a phone propped up next to the
bench. The PDF is still the one to print.

Full-resolution photographs of the whole build, including the shots that did not
make it into the guide, are in [`assembly_photos/`](assembly_photos).

**Before you start:** read [the bill of materials](BOM.md) and check every item is
on the bench. Quantities there are per completed gripper.

---

## Overview

The Magpie gripper is a versatile, 3D-printed robotic end-effector for precision
grasping and vision-based manipulation. Two Dynamixel AX-12A servos, controlled
through an OpenRB-150 board, drive a four-bar linkage (crank and rocker) that
keeps the fingers parallel through their whole range of motion. An Intel
RealSense D405 depth camera sits in the palm, which is what makes autonomous
grasping possible.

<div align="center">
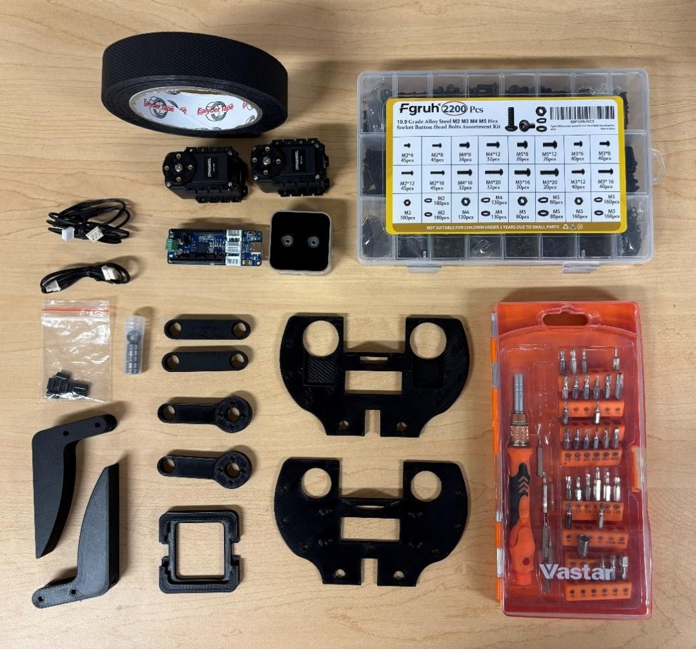
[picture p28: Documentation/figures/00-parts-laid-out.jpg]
Every part of the gripper laid out on a bench

</div>

## Safety

> [!CAUTION]
> **Disconnect all power before wiring or rewiring the AX-12A servos or the
> OpenRB-150 board.** Connecting power with reversed polarity permanently damages
> the servo electronics.

> [!WARNING]
> The parallel linkage and the fingers create severe pinch hazards. Never put your
> fingers or hands between the jaws or the linkages while the servos are powered.

- Work on a clean, static-safe, well-lit surface.
- Handle the RealSense D405 by the edges of its housing — not the lens or the IR emitters.
- Do not force fasteners. If a screw will not thread smoothly, back it out, check the alignment, and try again.
- Support a printed part near the hole you are fastening, so thin PLA walls do not crack.
- Keep clear of the jaws whenever the gripper is powered and under servo control.

## Tools (not included)

- 2 mm and 3 mm Allen keys
- A small flat-head screwdriver
- A USB-A to USB-C cable for the OpenRB-150

---

## Step 1 — Prepare the fingers

Cut the grip tape into two equal strips and press one firmly onto the inner
gripping surface of each finger. No air bubbles; edges flush with the plastic.

## Step 2 — Install the AX-12A servos

Seat the two servos in the mounting brackets on the bottom base with the splines
— the rotating output shafts — **facing inwards**. Secure each with four M2 nuts
and bolts.

<table>
<tr>
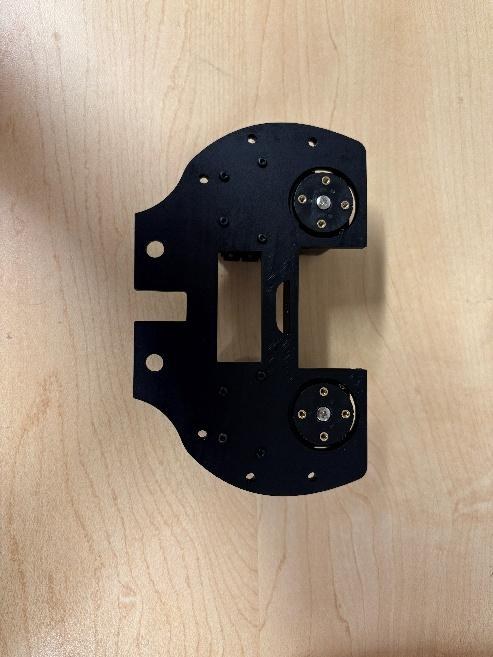
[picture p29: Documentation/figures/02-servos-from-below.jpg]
Bottom base with both servos installed, seen from below
<td></td>
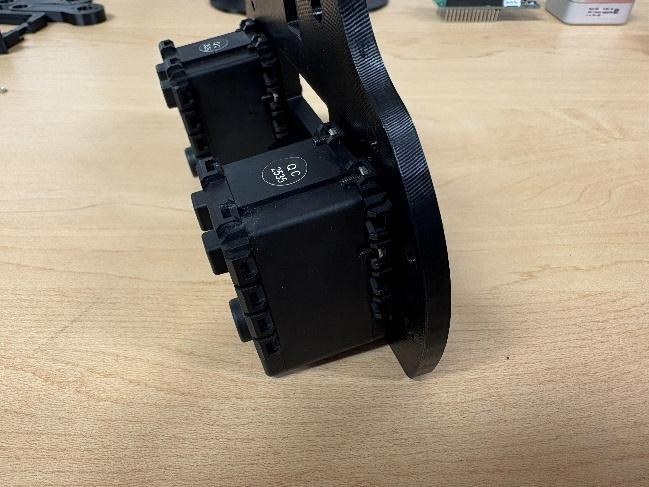
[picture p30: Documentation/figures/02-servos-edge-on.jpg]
The same pair of servos seen edge-on
<td></td>
</tr>
<tr>
<td align="center"><sub>Both servos installed, viewed from below, output horns visible.</sub></td>
<td align="center"><sub>The same pair edge-on, showing the flange screws.</sub></td>
</tr>
</table>

## Step 3 — Build the crank and coupler linkage

Press the 5 mm bearings into the circular housings in the servo cranks and
rockers — **two bearings per rocker, one per crank**.

<div align="center">
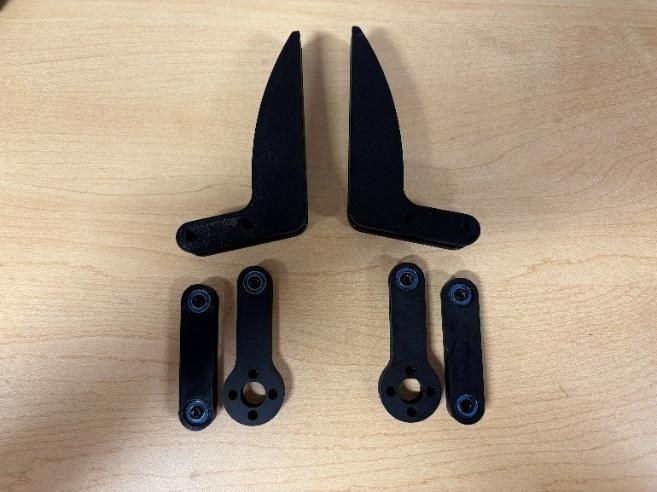
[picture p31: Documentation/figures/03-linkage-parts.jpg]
Fingers and rockers with bearings pressed in

</div>

Line the mounting holes in the base of each finger up with the end points of the
cranks and rockers, and secure them with M3 bolts. Work the linkage by hand and
check it moves smoothly before going on.

<div align="center">
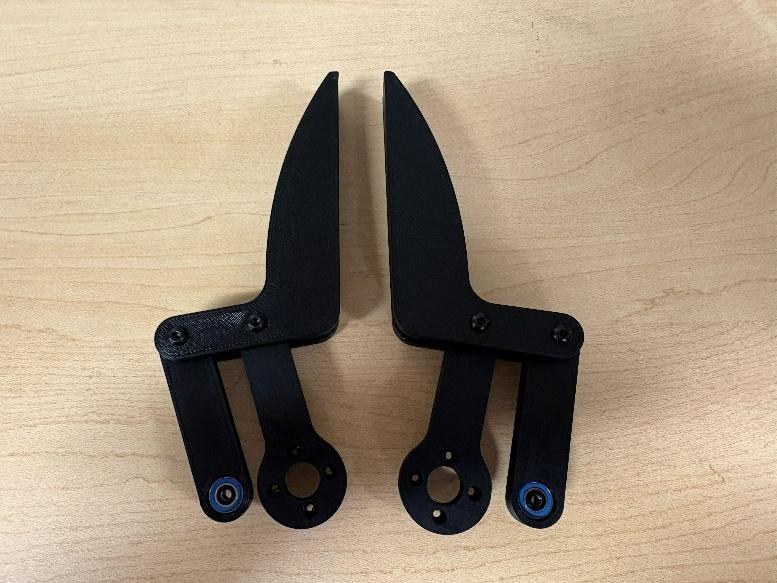
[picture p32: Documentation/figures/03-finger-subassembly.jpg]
A finger, coupler and rocker assembled into one subassembly

</div>

## Step 4 — Mount the servo rockers and fingers

Attach a servo crank to the installed servo's output horn with the horn screw
supplied with the AX-12A, plus four M2 bolts. **The notch on the servo must line
up with the arm.**

Connect the finger + coupler subassembly from step 3 to the crank's outer pivot
with M3 bolts and an 8 mm standoff, completing the four-bar linkage on this side.

<div align="center">
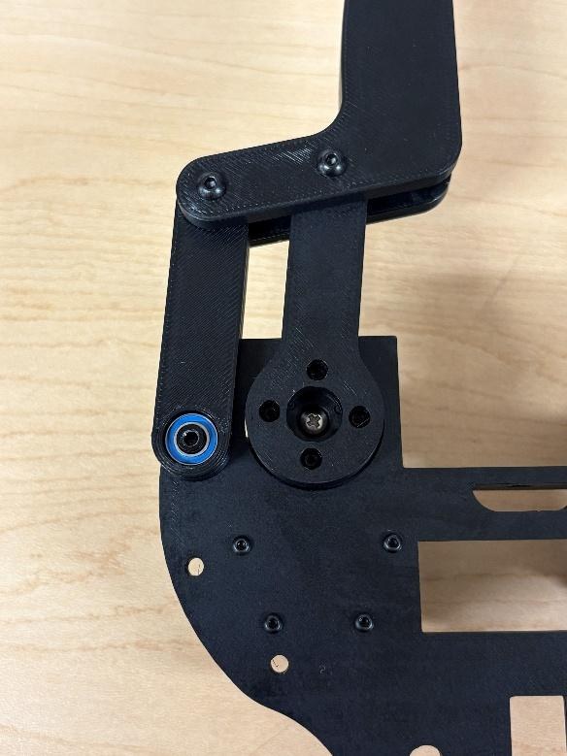
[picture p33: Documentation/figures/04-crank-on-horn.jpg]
Close-up of the crank fastened to the servo horn, bearing visible

</div>

## Step 5 — Repeat on the second side

Repeat steps 2 to 4 on the other side of the housing: lay out the second finger,
crank and coupler, pre-assemble the finger + coupler, and attach it to the second
servo's horn.

With both sides built, cycle each finger by hand and confirm the motion is smooth
and symmetrical before continuing.

<div align="center">
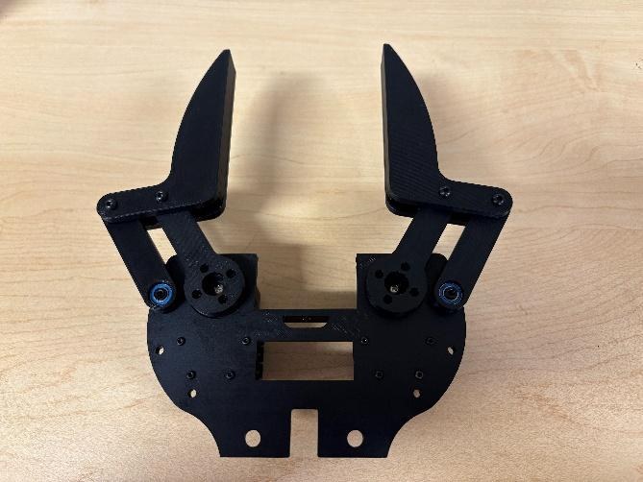
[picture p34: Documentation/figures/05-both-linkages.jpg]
Both linkages assembled on the bottom base

</div>

## Step 6 — Join the top base

Four M3 screws hold the top base to the rest of the assembly. There are further
holes for more standoffs and screws; they are not necessary.

<table>
<tr>
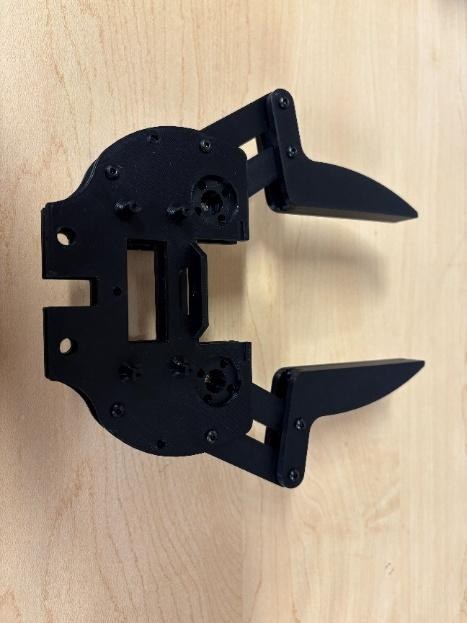
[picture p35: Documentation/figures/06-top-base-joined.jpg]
The top base screwed onto the assembly
<td></td>
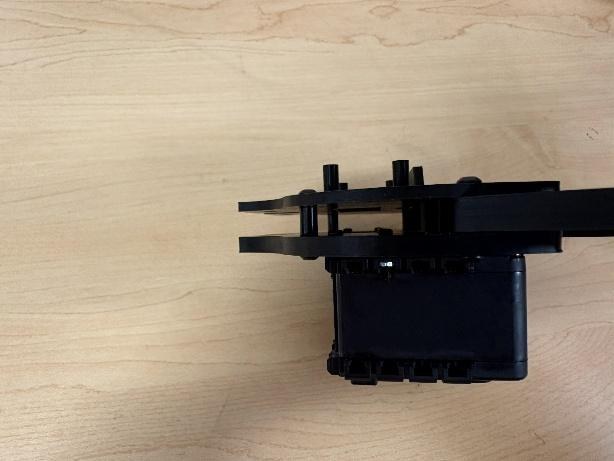
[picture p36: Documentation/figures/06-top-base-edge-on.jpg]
The joined assembly seen edge-on
<td></td>
</tr>
</table>

## Step 7 — Install the RealSense D405

Match the camera orientation to the figures, **cable facing the servo side**.
Do not use M3 screws longer than 6 mm here.

<table>
<tr>
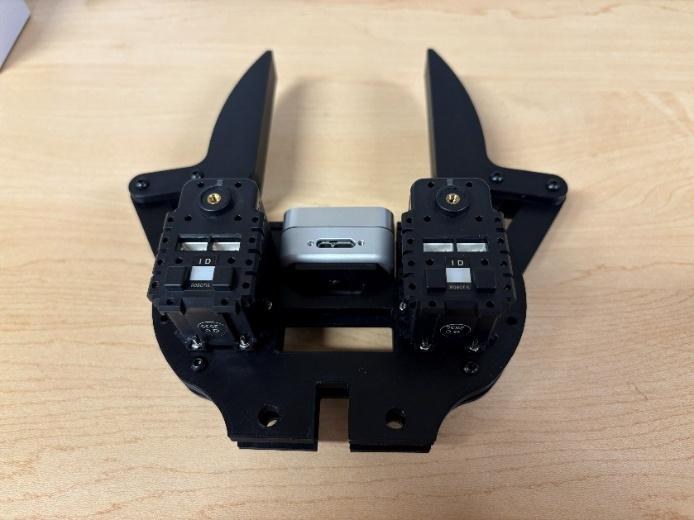
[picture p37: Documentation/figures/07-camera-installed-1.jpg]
The D405 camera mounted in the palm
<td></td>
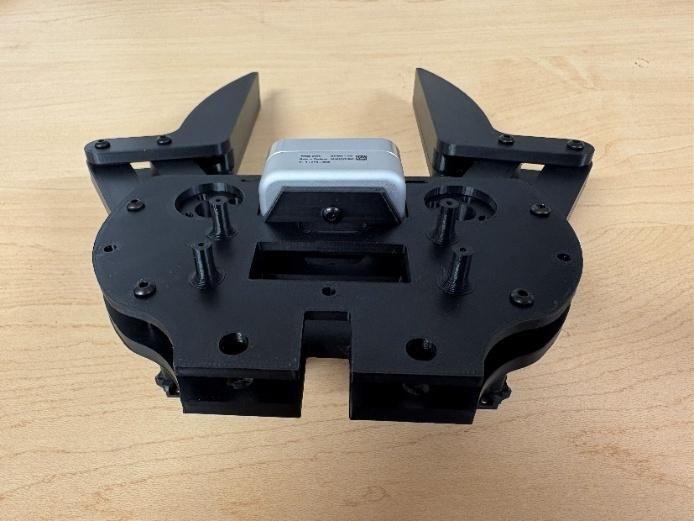
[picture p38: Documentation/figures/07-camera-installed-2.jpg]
The mounted camera from a second angle
<td></td>
</tr>
</table>

## Step 8 — Install the OpenRB-150

Four M2 screws. The printed part is not threaded, so it helps to drive the screws
into the plastic once before mounting the board.

<div align="center">
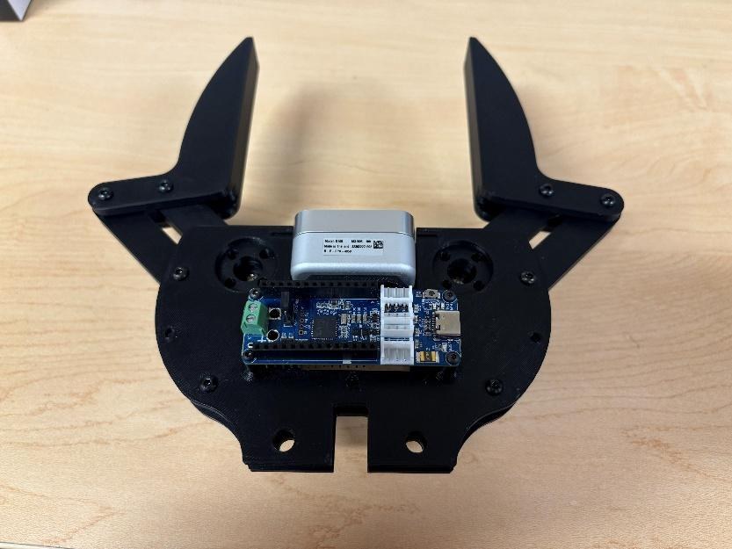
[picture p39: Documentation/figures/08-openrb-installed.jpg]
The OpenRB-150 board mounted on the gripper

</div>

## Step 9 — Fit the camera protector

Orientation matters, because the top and bottom plates are different sizes. Find
the right way round and snap the part in with reasonable pressure.

<table>
<tr>
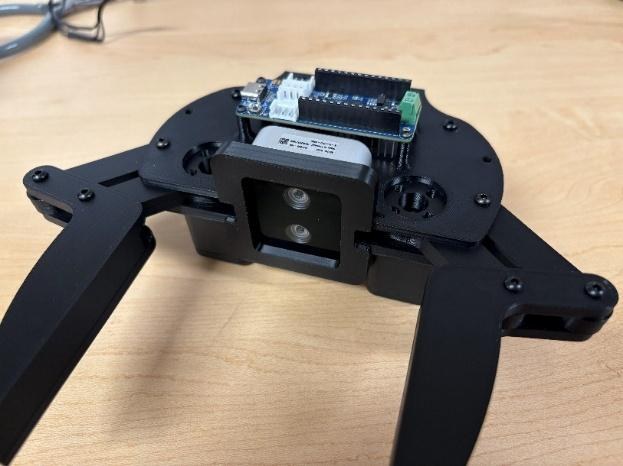
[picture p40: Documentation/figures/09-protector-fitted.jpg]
The camera protector fitted to the gripper
<td></td>
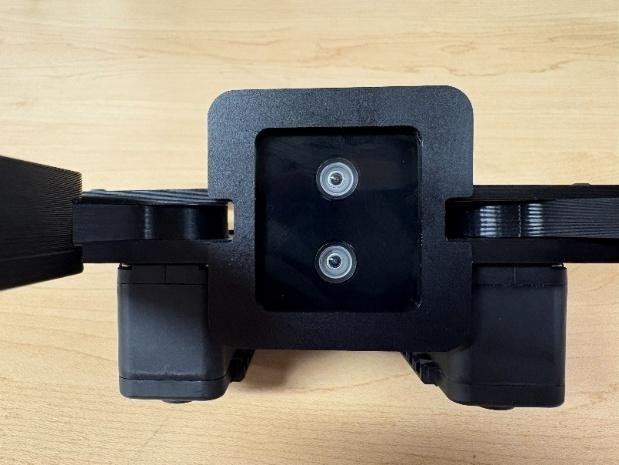
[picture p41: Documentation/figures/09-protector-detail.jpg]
Close-up of the fitted camera protector
<td></td>
</tr>
</table>

## Step 10 — Wiring, cable routing and addresses

Route the EH-to-Molex cable through both base plates: the EH connector goes to the
OpenRB-150, the Molex connector to one of the servos.

<div align="center">
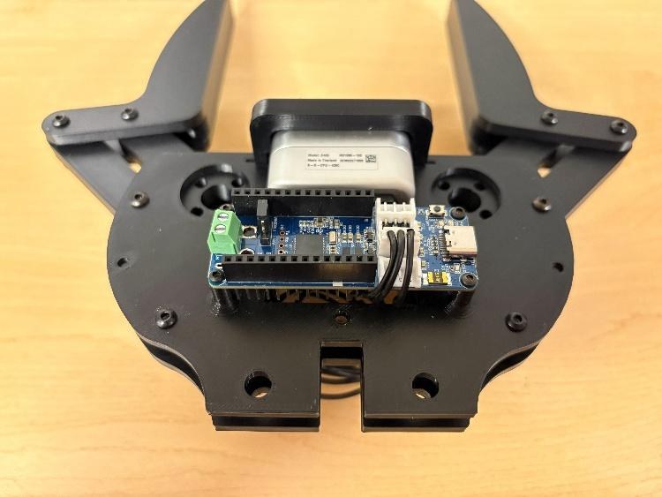
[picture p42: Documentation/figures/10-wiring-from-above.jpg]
The wired gripper seen from above

</div>

**Servo addresses.** In the orientation above — board on top — the **right servo is
ID 1** and the **left servo is ID 2**. Servos ship set to ID 1, so setting the
addresses usually means connecting one servo at a time. Use
[Dynamixel Wizard 2.0](https://emanual.robotis.com/docs/en/software/dynamixel/dynamixel_wizard2/),
and connect the left servo first. While you have a servo connected, set its
maximum clockwise and counter-clockwise positions — that is what keeps it from
stalling against the mechanism.

**Camera calibration.** Set the D405 up a known distance from a surface and enter
that distance, using the RealSense Viewer from the
[RealSense repository](https://github.com/IntelRealSense/librealsense).

<table>
<tr>
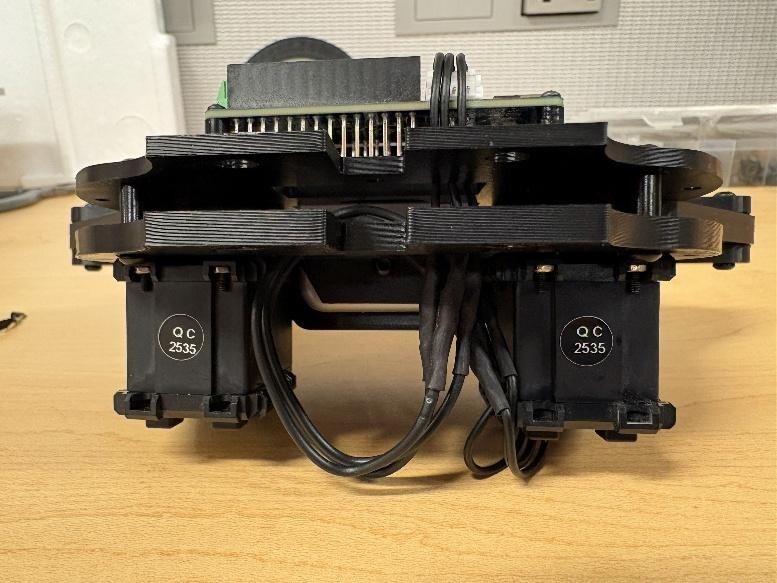
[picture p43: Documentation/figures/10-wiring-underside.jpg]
Cable routing seen from the underside
<td></td>
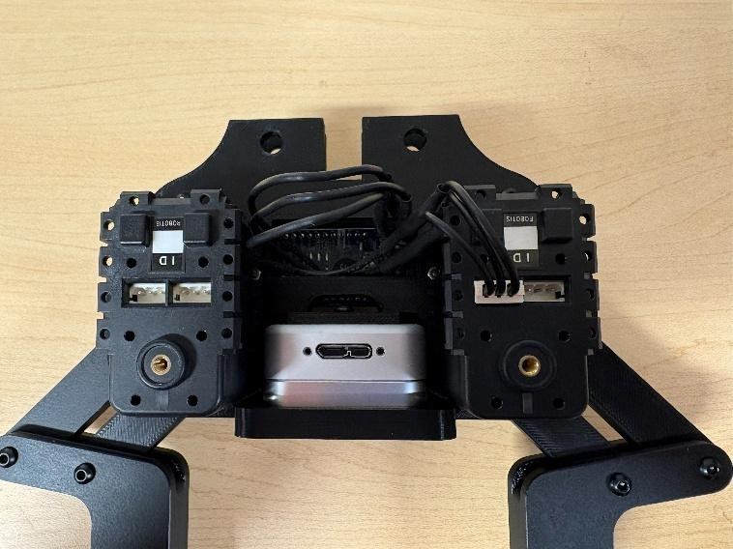
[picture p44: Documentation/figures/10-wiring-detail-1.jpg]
Detail of the cable routing between the plates
<td></td>
</tr>
</table>

<div align="center">
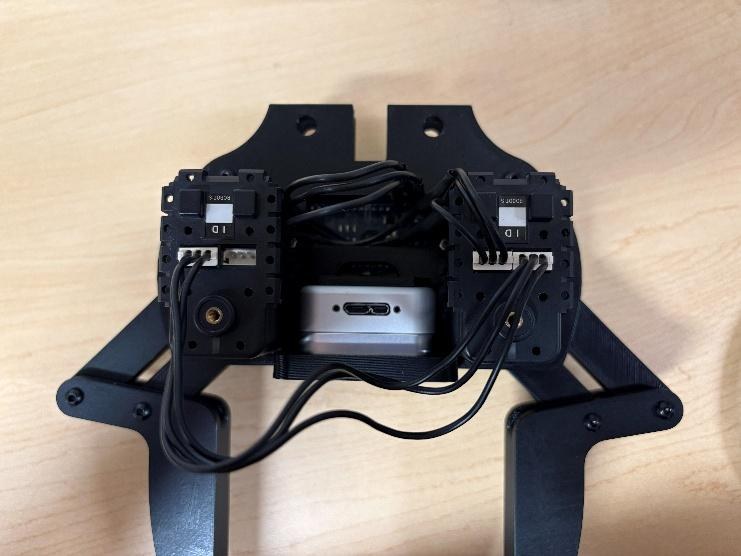
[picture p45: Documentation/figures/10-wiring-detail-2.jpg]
Second detail view of the routed cables

</div>

## Step 11 — Final hardware check

- Cycle each finger by hand, unpowered, through its full open and close range. The
  motion should be smooth, with no binding at the coupler or rocker pivots.
- Recheck that every M3 and M2 fastener from steps 1–7 is snug, and that no
  standoff has backed out of the bottom base.

---

## Troubleshooting

| Symptom | What to check |
| --- | --- |
| **Fingers do not move symmetrically** | Both cranks must be installed with the servo horns centred. A horn fitted off-centre makes one jaw lead the other. |
| **Binding or rough motion in the linkage** | Loosen the affected coupler or rocker fastener slightly. Pivots should turn freely with little or no axial play — not be clamped tight. |
| **OpenRB-150 does not detect a servo** | Check the daisy-chain wire orientation and that both connectors are firmly seated, at the servo and at the board. Confirm the servo's baud rate and ID match your control software. |
| **Camera not detected over USB** | Reseat the D405 connector. An overtightened cable screw stresses the internal cable. |

## Calibration

Both the RealSense D405 and the AX-12A servos are calibrated in
[step 10](#step-10--wiring-cable-routing-and-addresses).

## Maintenance

- Inspect the M3 and M2 fasteners periodically — vibration loosens them — and re-torque as needed.
- Clean the D405 lens with a microfibre cloth only. No solvents.
- Check the 5 mm bearings for smooth rotation every few hundred grip cycles, and replace them if roughness or play develops.
- Store the gripper with the fingers open, to keep preload off the linkage.

---

Once it is together, the software that drives it — force control, the palm
camera, grasping and planning — lives in
[correlllab/MAGPIE](https://github.com/correlllab/MAGPIE).

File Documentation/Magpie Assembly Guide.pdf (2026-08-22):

# Magpie Gripper V2 Assembly

Overview
The Magpie Gripper is a versatile, 3D-printed robotic end-effector designed for precision grasping and vision-based manipulation. Driven by Dynamixel AX-12A servo motors and controlled via an OpenRB-150 board, the gripper utilizes a four-bar linkage system (crank and rocker) to ensure the fingers remain parallel throughout their entire range of motion. Additionally, it integrates an Intel RealSense D405 depth camera, allowing for advanced computer vision and autonomous grasping applications.

Safety & General Guidelines
CAUTION: Disconnect all power sources before wiring or rewiring the AX-12A servos or the OpenRB-150 board. Connecting power with reversed polarity can permanently damage the servo electronics.
Observe the following precautions throughout assembly:
- Work on clean, static-safe, well-lit surface
- Handle the Intel RealSense D405 by its housing edges only – avoid touching lens or IR emitters
- Do not force fasteners. If a screw does not thread smoothly, back it out, verify alignment, and retry
- Support printed parts near the hole being fastened to avoid cracking thin PLA walls
- Keep fingers clear of jaw mechanism when the gripper is powered and under servo control
- The parallel linkage mechanism and the gripping fingers create severe pinch hazards. Never place your fingers or hands between the jaws or the mechanical linkages while the servos are powered.

Bill of Materials
Verify that every item below is present before starting assembly. Quantities are per single completed gripper.

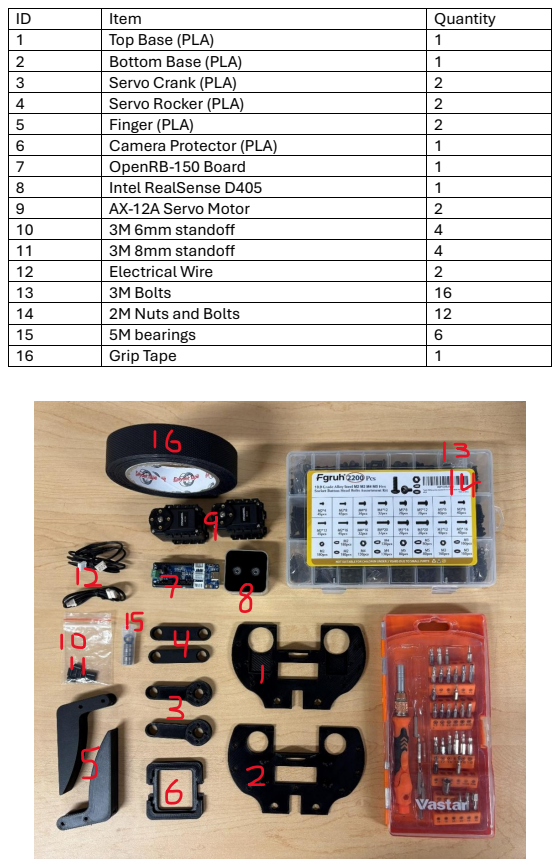
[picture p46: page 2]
Item; Quantity 1; Top Base (PLA); Bottom Base (PLA); Servo Crank (PLA); Servo Rocker (PLA); Finger (PLA); Camera Protector (PLA); OpenRB-150 Board; Intel RealSense D405; AX-12A Servo Motor; 3M 6mm standoff; 3M 8mm standoff; Electrical Wire; 3M Bolts; 2M Nuts and Bolts; 5M bearings; Grip Tape

Tools Required (Not Included)

- 2M and 3M Allen keys
- Small flat-head screw driver
- USB A to USB C cable for the OpenRB-150

Assembly Instructions
Step 1: Prepare the fingers
Begin by cutting the grip tape into two equal strips. Apply one strip firmly to the inner gripping surface of each finger. Ensure that there are no air bubbles and the edges are flush with the plastic.
Step 2: Install the AX-12A Servo motors
Align the two AX-12A servo motors into the designated mounting brackets on the bottom base. Ensure the servo splines (the rotating output shafts) are facing inwards. Secure each motor using 4 2M nuts and bolts respectively.

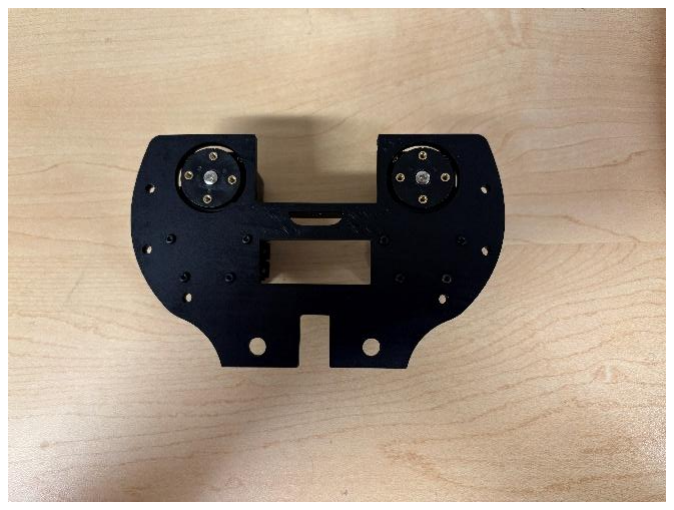
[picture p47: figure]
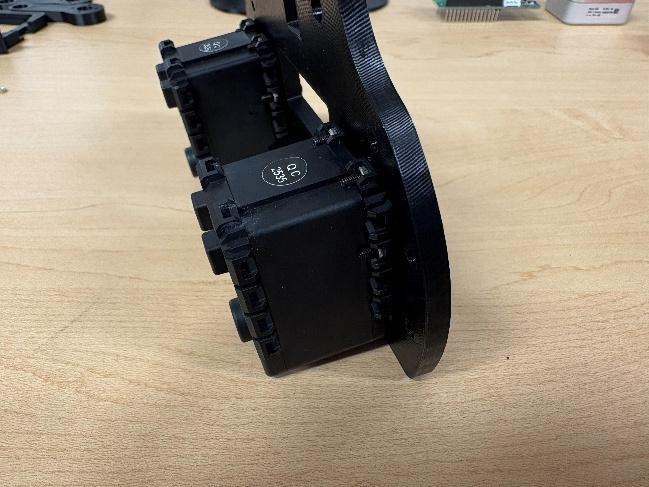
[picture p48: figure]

Figure 1 -- Left: Bottom base with both AX-12A servos installed, viewed from the bottom with both output horns visible. Right: the same pair of servos viewed edge-on, showing the flange screws that secure each to the housing.

Step 3: Build the crank & coupler linkage

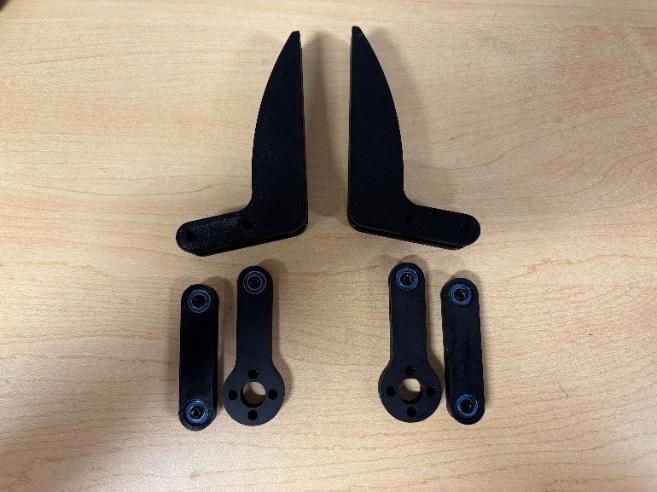
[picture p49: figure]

Press the 5M bearings into the circular housing slots on the servo cranks and servo rockers. Two bearings per rocker and one per servo crank

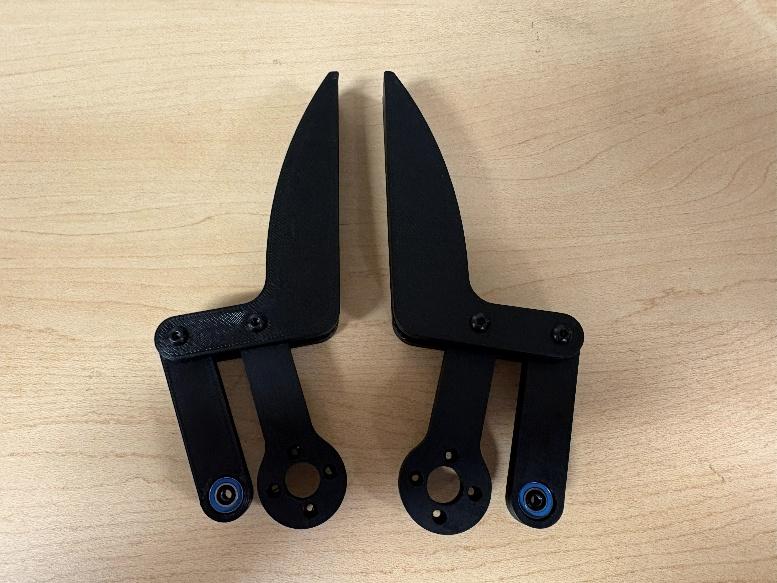
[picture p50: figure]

Align the mounting holes on the base of the fingers with the end-points of the servo cranks and rockers. Secure them using 3M bolts. Manually actuate the linkages to ensure smooth operation

Step 4: Mount the servo rockers and fingers
Attach a servo crank to the installed servo’s output horn using the horn screw supplied with the AX-12A servo as well has 4 2M bolts. Make sure the notch of the servo is in line with the arm.
Connect the finger + coupler subassembly from step 3 to the crank’s outer pivot with 3M bolts and a 8mm standoff, completing the four bar linkage on this side

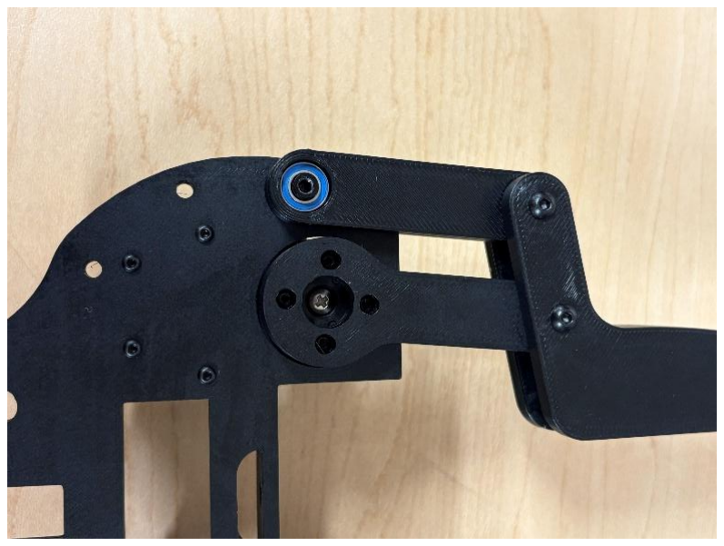
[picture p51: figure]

Step 5: Repeat the Linkage on the Second Side
Repeat Steps 2 through 5 on the opposite side of the housing: lay out the second finger, crank, and coupler pair, pre-assemble the finger + coupler assembly, and attach it to the second servo’s horn
With both sides complete, cycle each finger by hand to confirm smooth, symmetrical motion on both linkages before continuing.

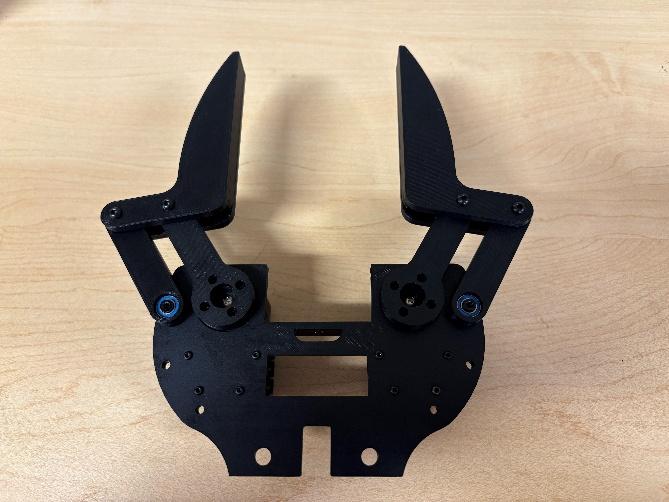
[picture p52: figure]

Step 6: Join the top base
Screw in 4 M3 screws to connect the top base to the rest of the assembly. There are additional holes for more standoffs and screws, but this is not necessary.

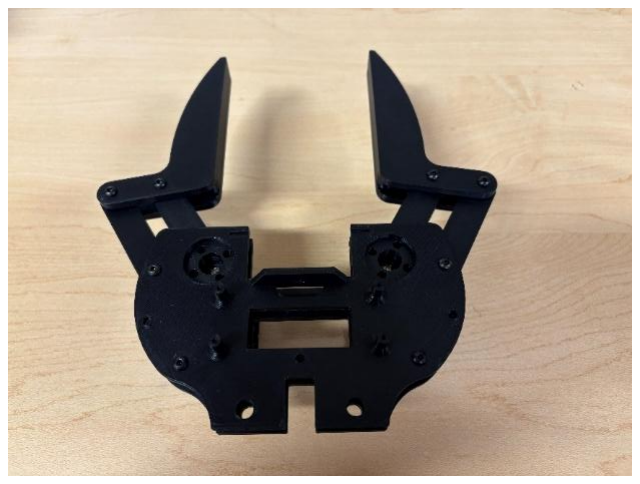
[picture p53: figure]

Step 7: Install the Intel RealSense D405 camera

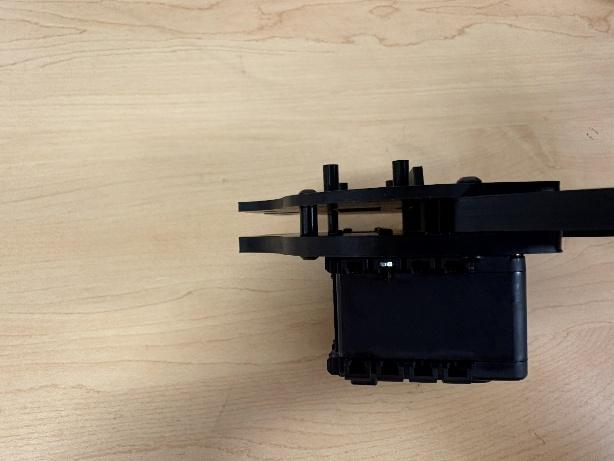
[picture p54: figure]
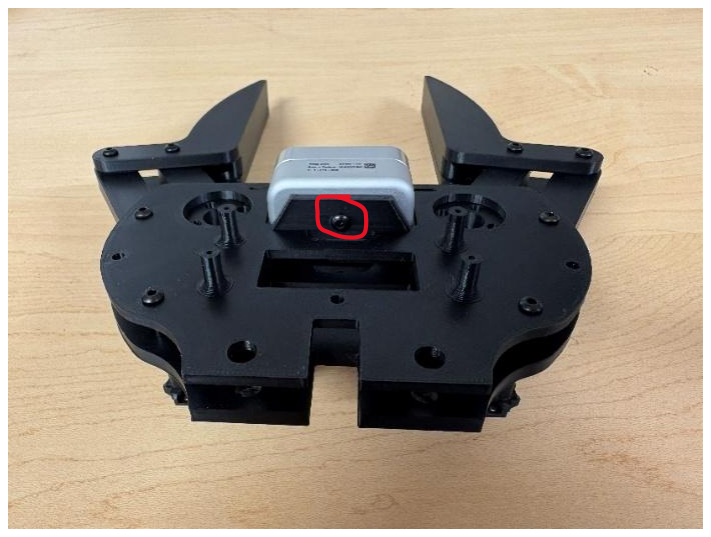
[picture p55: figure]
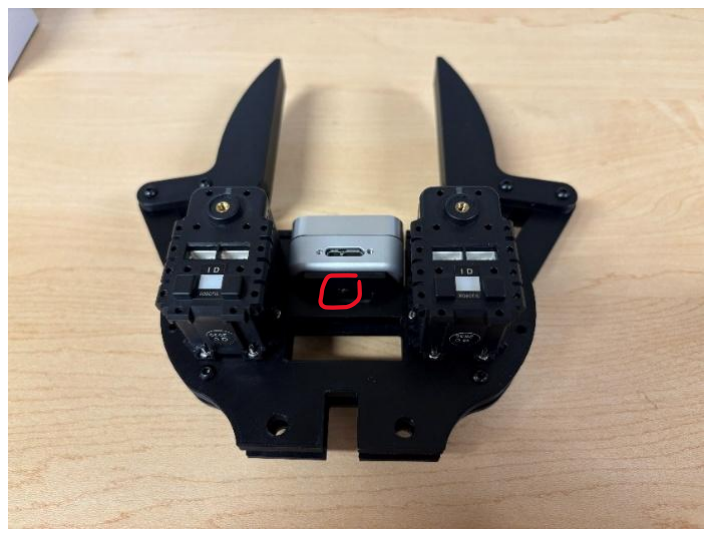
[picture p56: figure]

Make sure the camera orientation matches the figures with the cable facing the side of the servos. Do not use M3 screws larger than 6mm for this.

Step 8: Install the OpenRB-150 controller

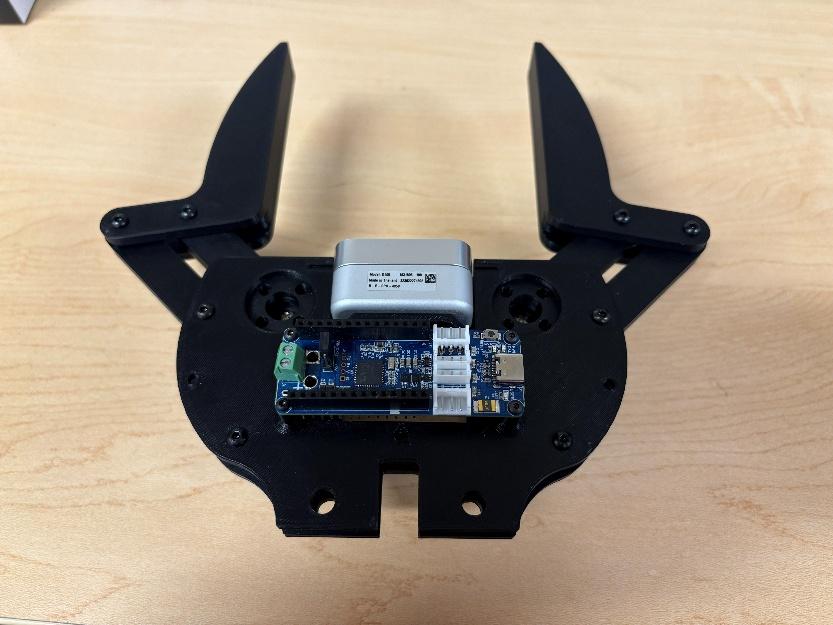
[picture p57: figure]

Use 4 M2 screws for this. Since the 3D printed part is not threaded, you may want to drive screws into the part before mounting the board.

Step 9: Install camera protector

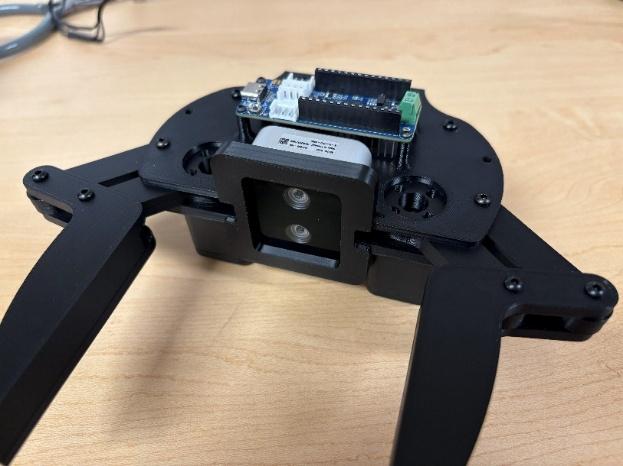
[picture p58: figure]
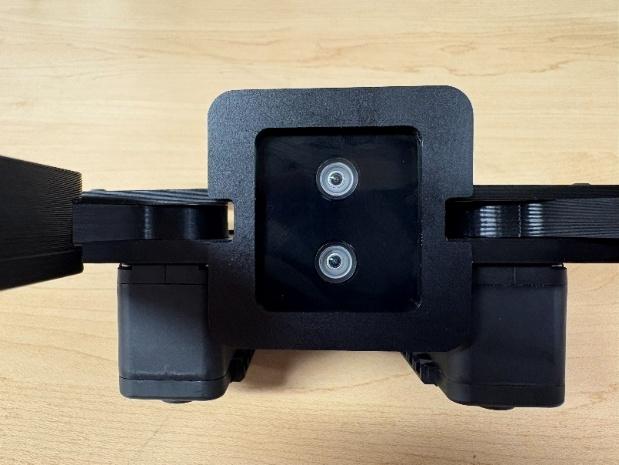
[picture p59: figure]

Orientation of this part matters due to different sized top and bottom plates. Find the right orientation and snap in the part by applying reasonable pressure.

Step 10: Wiring and Cable Routing

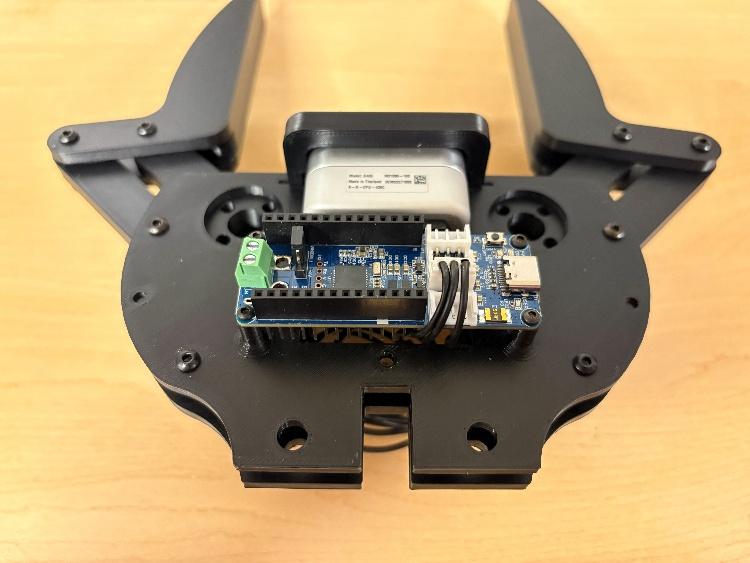
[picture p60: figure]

The EH to Molex cable should be routed through both base plates with the EH connector going to the OpenRB-150 board and the Molex connector to one of the servos.
Servos should be set with specific addresses with the right servo (in the orientation above with the board on top) set to ID 1, and the left servo set to ID 2. By default, servos are set to ID 1, so setting correct addresses may require connecting only one servo at a time. It is recommended to use Dynamixel Wizard 2.0 and to only connect the left servo first. While connected to a servo, max clockwise and counterclockwise positions can be set to minimize the chance of stalling a servo.
Also, the D405 camera should be calibrated by setting it up a known distance away from the surface and entering that information in. This can be done using the RealSense Viewer found in the RealSense repository.

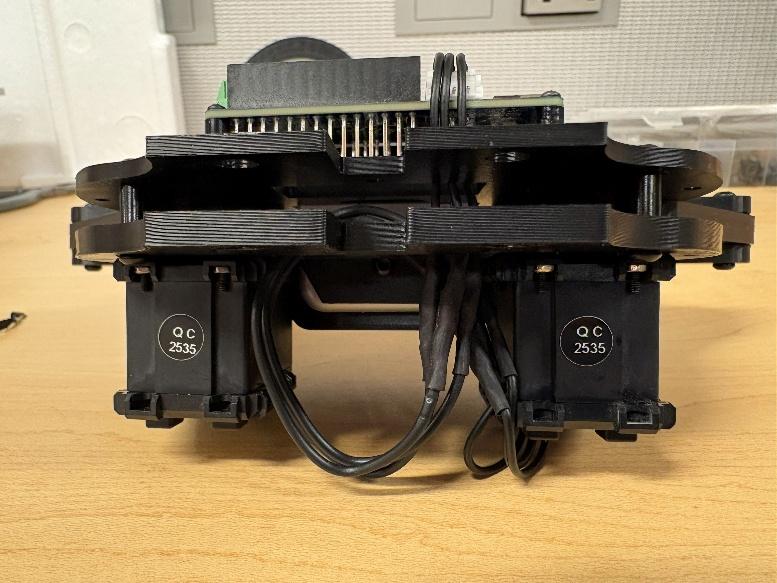
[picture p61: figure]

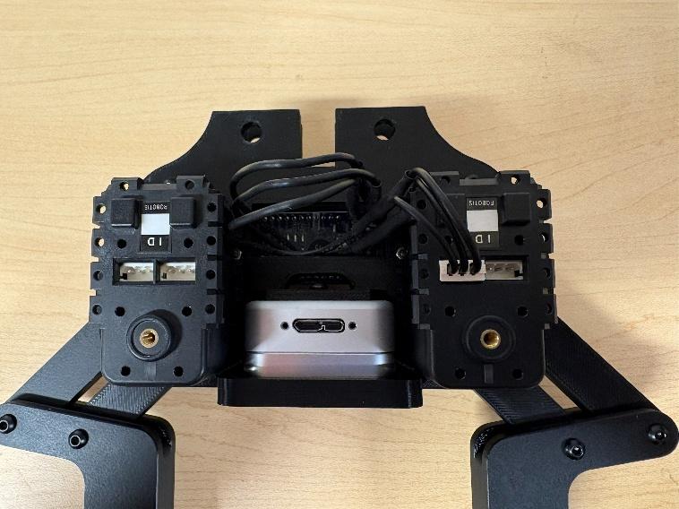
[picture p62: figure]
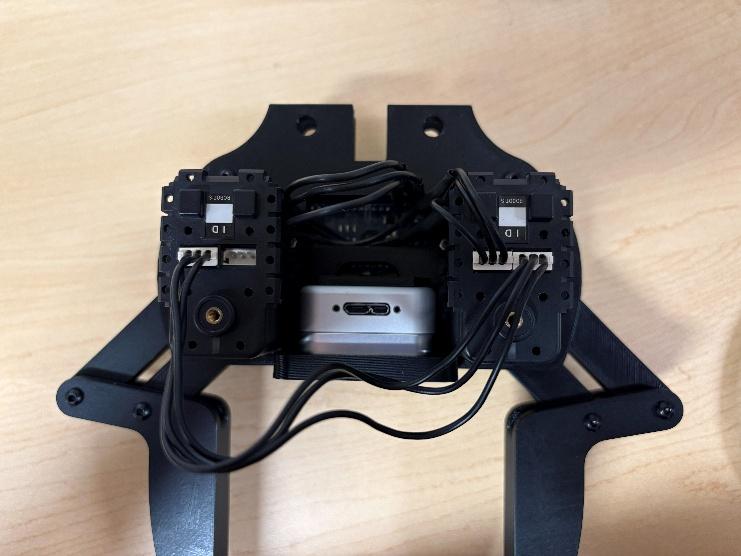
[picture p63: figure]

Step 11: Final hardware check
Cycle each finger by hand (with gripper unpowered) through its full open and close range, confirming smooth motion with no binding at the servo coupler or rocker pivots
Recheck that all 3M and 2M fasteners used across Steps 1-7 are snug, and that no standoffs have backed out of the bottom base

Troubleshooting
Fingers do not move symmetrically
- Re-check that both servo cranks were installed with the servo horns centered before assembly. A horn installed off-center will cause one jaw to lead the other
Binding or rough motion in the linkage
- Loosen the affected servo coupler or rocker fastener slightly – pivots should rotate freely with zero to minimal axial play, not be clamped tight
OpenRB-150 does not detect a servo
- Verify the daisy-chain wire orientation and check for a firm connector seat at both the servo and the board. Confirm the servo’s baud rate and ID match your control software’s configuration
Camera not detected over USB
- Reseat the Intel RealSense D405 USB connector and confirm the cable screw was not overtightened, which can stress the internal cable

Calibration
For calibration of the RealSense D405 and the Dynamixel AX-12A servos, refer to step 10 of the assembly.

Maintenance

- Periodically inspect all 3M and 2M fasteners for loosening due to vibration and re-torque as needed
- Clean the Intel RealSense D405 lens with a microfiber cloth only – avoid solvents
- Check 5M bearings for smooth rotation every few hundred grip cycles; replace is roughness or play develops
- Store the gripper with fingers in the open position to minimize preload on the linkage when not in use

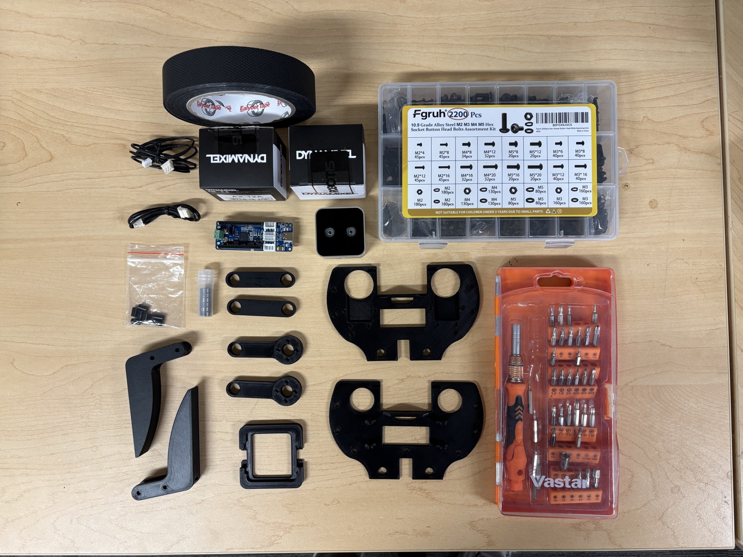
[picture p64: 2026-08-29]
Documentation/assembly_photos/IMG_4985.jpg

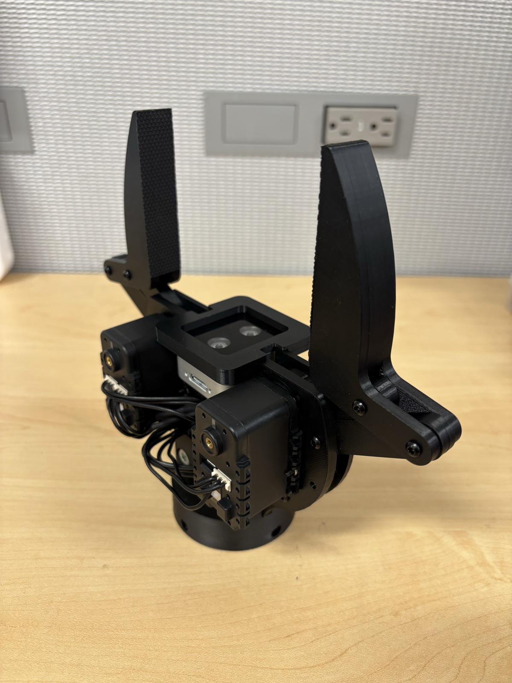
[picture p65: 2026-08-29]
Documentation/assembly_photos/IMG_5020.jpg

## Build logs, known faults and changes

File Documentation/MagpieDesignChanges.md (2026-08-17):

# Magpie Design Changes and Reasoning

## Major Design Changes

### CAD Assembly
| Old | New |
|---|---|
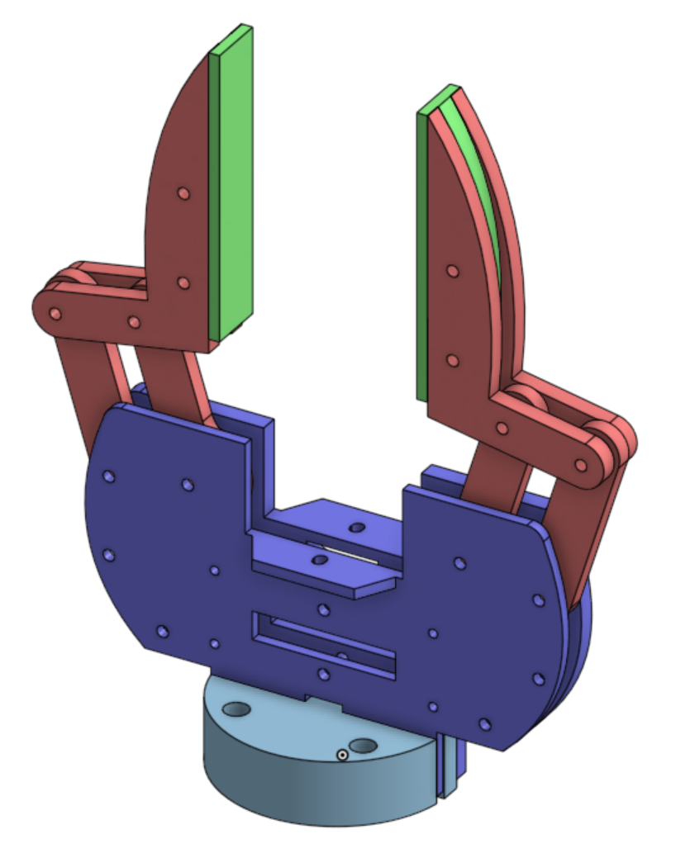
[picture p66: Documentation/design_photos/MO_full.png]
Old assembly
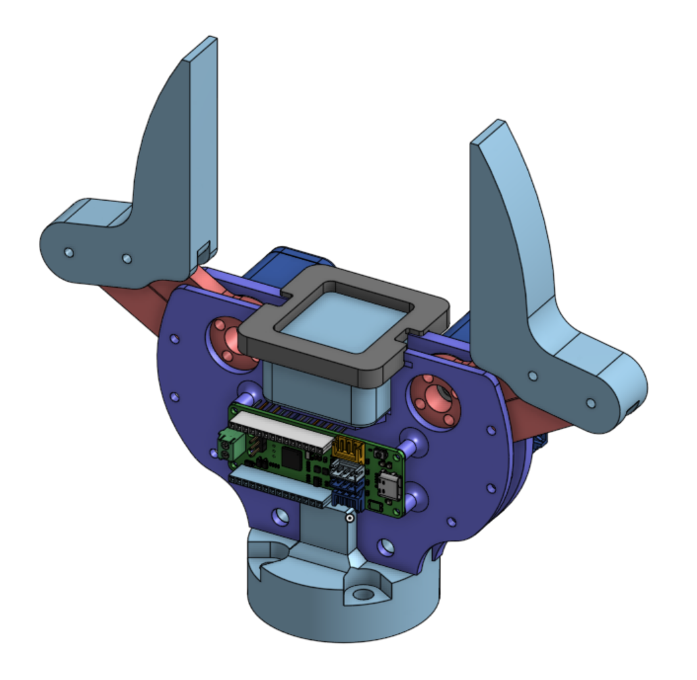
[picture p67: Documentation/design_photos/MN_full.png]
New assembly
|  |  |

### Camera Mount: Sliders to Holes
Changed the camera mount from sliders to holes. This allows the camera to be mounted in a repeatable position, which is important for accuracy when grabbing objects.

| Old (sliders) | New (holes) |
|---|---|
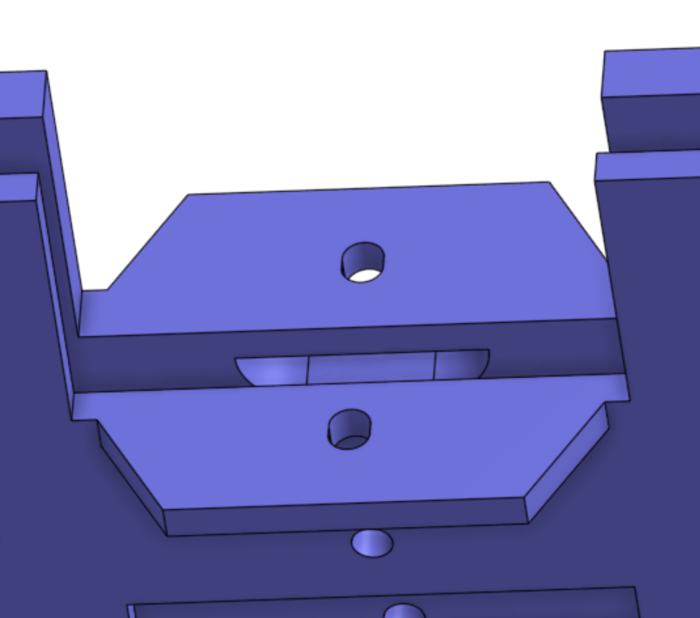
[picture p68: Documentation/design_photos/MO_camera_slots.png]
Old camera mount with sliders
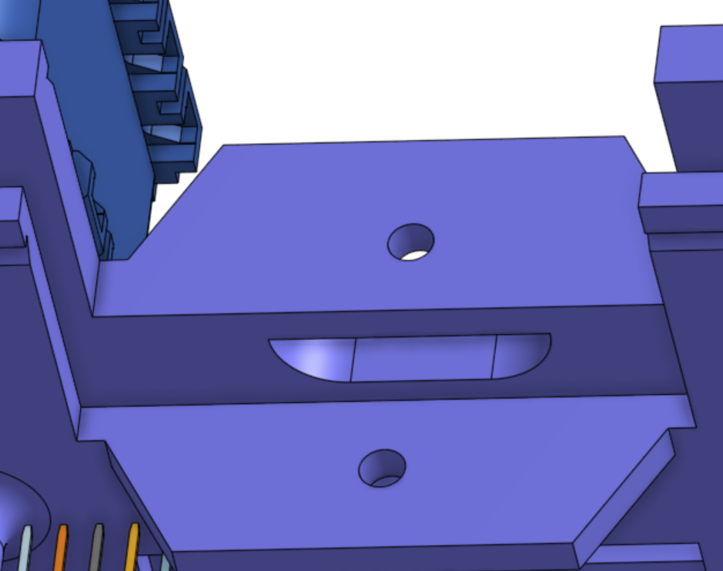
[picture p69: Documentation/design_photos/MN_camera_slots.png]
New camera mount with holes
|  |  |

### Crank Access Holes
Added holes to access the screws on the crank. The rocker and crank are the weakest 3D-printed parts of the gripper. If the crank breaks, these access holes mean it can be removed without fully disassembling the gripper.

| Old (no access holes) | New (access holes) |
|---|---|
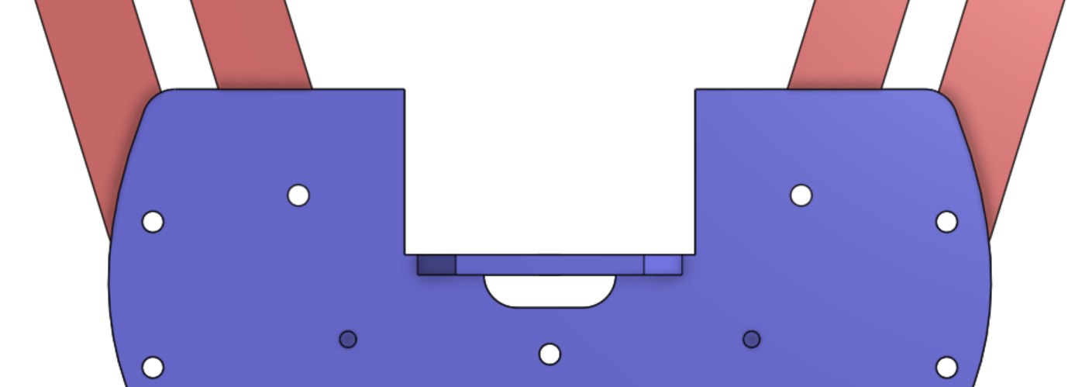
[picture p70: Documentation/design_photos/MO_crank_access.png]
Old crank without access holes
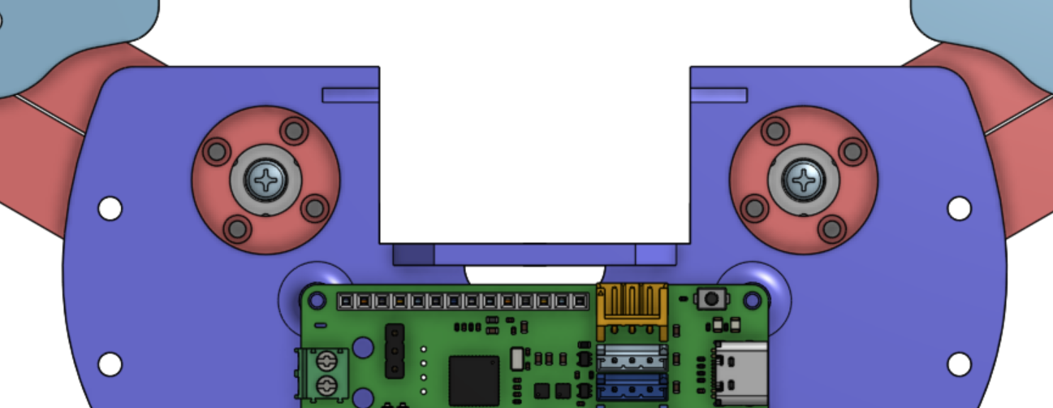
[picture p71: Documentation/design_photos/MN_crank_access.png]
New crank with access holes
|  |  |

### Fingers Combined into a Single Part
The fingers originally consisted of three separate parts. This design allowed the contact surface (the part that touches the object being picked up) to be printed separately in TPU. Combining the fingers into a single part simplifies both the design and assembly, but it requires grip tape to be added to maintain the same performance.

| Old (three part finger) | New (one part finger) |
|---|---|
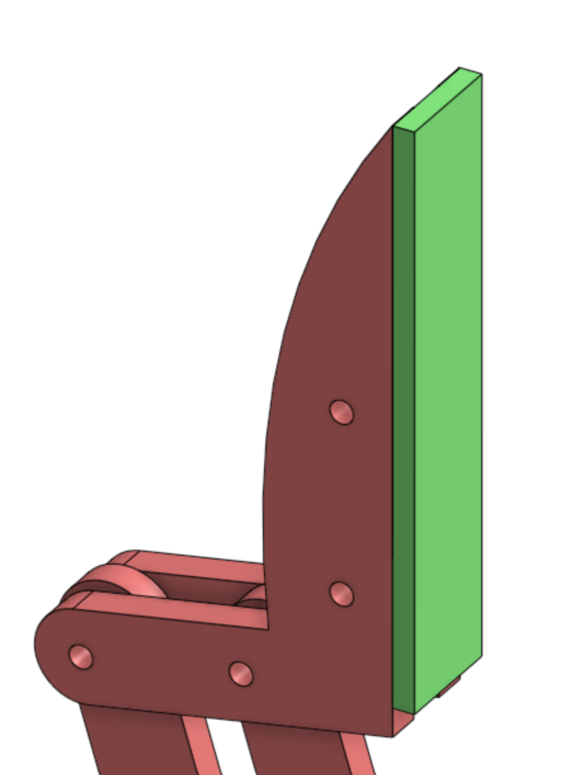
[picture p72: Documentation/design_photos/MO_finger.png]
Old three-part finger design
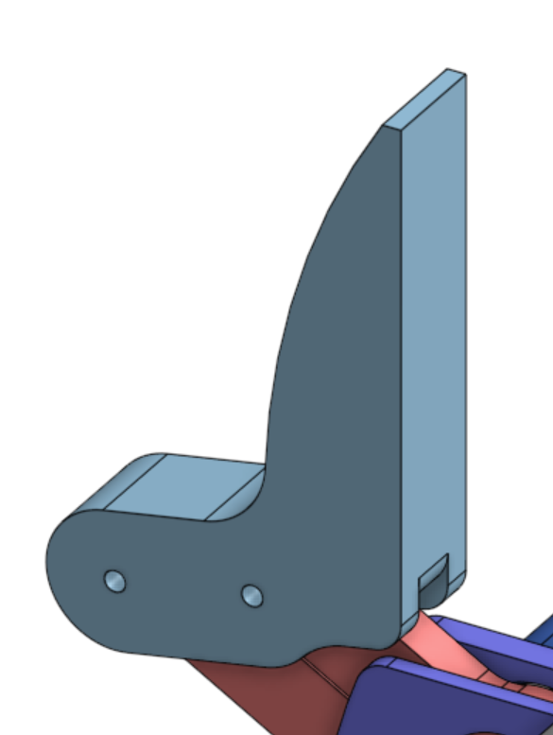
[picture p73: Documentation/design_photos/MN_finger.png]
New one_part finger design
|  |  |

### Increased Rocker and Crank Thickness
Since the rocker and crank are the weakest parts of the system, their thickness was increased to maximize strength within the available space constraints. These parts should be printed with at least 50% infill.

Additionally, the crank originally included extra height in the section that connects to the servo, which conflicted with the servo footprint. This required assembly with 8mm standoffs instead of the 6mm standoffs shown in the CAD assembly. Given our current stock of standoffs and the goal of maximizing the strength of the rocker and crank, revision two of the Magpie gripper was designed around 8mm standoffs.

### Base Top and Bottom Changes
- **Increased cable pass-through hole:** Makes assembly and disassembly easier.
- **Changed OpenRB-150 mounting:** Originally required additional standoffs; the 3D-printed design now has standoffs built in. There may be strength concerns, since this is a small section with unfavorable layer-line orientation.
- **Repositioned OpenRB-150 mounting:** Moved away from nearby screws to leave more room for wires.
- **Modified shape near the base:** The original design had an abrupt transition connecting the mounting holes to the rest of the gripper, which appeared to be a weak point. Additional material was added to create a more gradual transition and increase strength.

| Old | New |
|---|---|
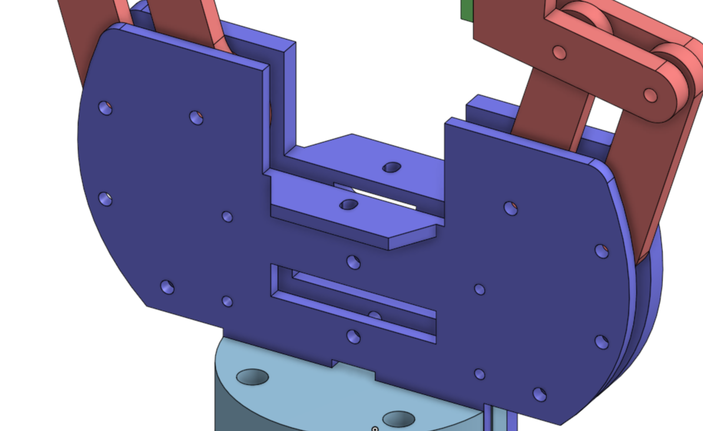
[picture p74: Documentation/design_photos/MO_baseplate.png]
Old baseplate design
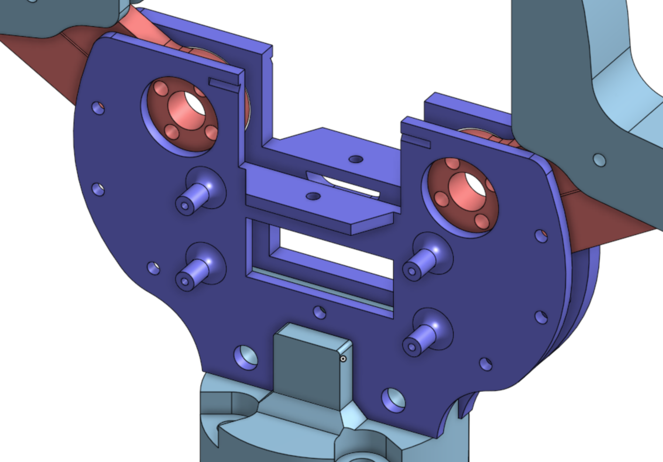
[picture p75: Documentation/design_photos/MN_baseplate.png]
New baseplate design
|  |  |

### Camera Cover
Changed the camera cover from two separate parts screwed in on either side to a single part that snaps onto the top. This may raise concerns about how well it protects the camera and servos from foreign object debris (FOD), which could require a full enclosure.

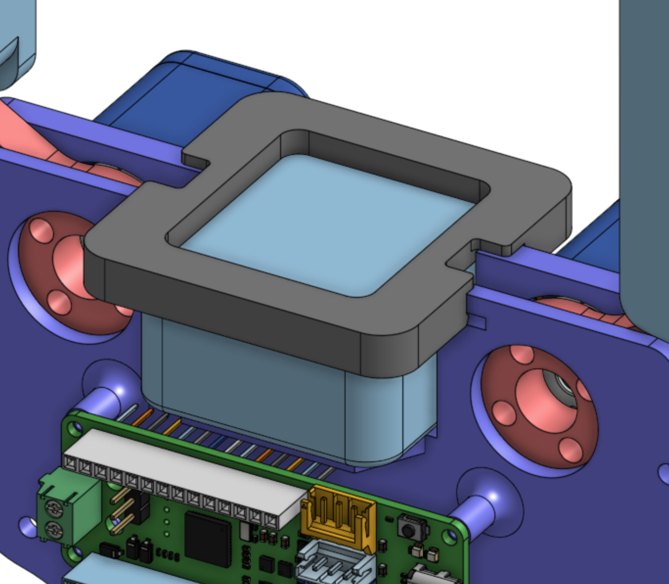
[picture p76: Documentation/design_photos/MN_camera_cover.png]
New single-piece camera cover

<!-- TODO: add photo of old two-piece camera cover (missing CAD assembly) -->

### Wire Cover
Added a wire cover to help protect the servo and camera cables while bracing against the arm.

### New H1-2 Mount
Simplified the H1-2 mount, as the original design was more complex than necessary. The main concern is that the new part is weaker than the original mount; printing with higher infill could help address this.

### Smaller Design Changes:
- Added fillets to OpenRB-150 standoffs
- Added small divots in both sides of the base plates for camera cover
- Increased the size of M3 holes to 3.4mm to avoid threading 3D printed parts
- Added a cover for the finger part to reduce play and increase strength

## Current Work

### New UR5 Mount
Testing a new UR5 mount intended to simplify mounting and removal. Outstanding concerns include:
- Potential weak points due to limited space and layer-line orientation.
- Screws that may block one another.

<!-- TODO: add photo of new UR5 mount -->

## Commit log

2026-08-13 V1
    Added details about the 3D models and printing guidelines.
2026-08-13 V1
    Added assembly manual and BOM details to README.
2026-08-13 Add finger V2
    [Finger V2 - Silicone Finger Mold.stl, Finger V2 - Silicone Finger.stl]
2026-08-13 type: uploaded assembly photos
2026-08-13 Add Finger V3
    [Finger V3 - Finger+Coupler.stl]
2026-08-14 doc to hold design changes for the magpie grippers
2026-08-17 Revise Bill of Materials included Old and New (incomplete)
2026-08-18 Update BOM 1
    Updated item quantities and corrected trademark symbols in BOM.
2026-08-18 Update BOM 2 (old magpie total + magpiev2 prices)
2026-08-18 Revise BOM title and section headers
2026-08-18 Revise BOM to Version 2
2026-08-18 Add PLA printing note to BOM documentation
2026-08-18 Update BOM costs (incomplete)
2026-08-19 Update BOM costs2 (incomplete)
2026-08-20 Modify printing guidelines in README
2026-08-20 Revise README with updated information and details
    Updated the date and improved descriptions for the assembly manual and BOM. Added section for design changes.
2026-08-20 Enhance BOM with filament weight
    Updated BOM to include filament weight and revised infill details.
2026-08-20 Revise BOM format and add Version 2 details
    Updated the cost table format and added missing filament information for Version 1. Adjusted costs and added a new Version 2 with updated details.
2026-08-20 Revise BOM for Magpie Gripper with updated costs
    Updated the Bill of Materials (BOM) for the Magpie Gripper with new cost estimates and quantities for parts in Version 2. Adjusted infill settings and removed filament weight column.
2026-08-20 Adjust total cost in BOM after item removal
2026-08-29 Make the build readable without downloading anything
    The guide, the models and the photographs were all here; none of them
    rendered on GitHub. The manual was a PDF, the build photos were HEIC —
    which GitHub will not preview and Windows and Linux often will not open —
    and the STLs were twelve file names.
    - Documentation/assembly.md: the assembly guide as Markdown, figures
    inline, so it reads on the phone propped up next to the bench. The PDF
    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
2026-08-29 Put the hardware under MIT, like the software
    The models, the bill of materials and the assembly guide had no licence at
    all, which in a public repository means nobody may safely print from them —
    the opposite of what an open-hardware repo is for. Same MIT terms as
    correlllab/MAGPIE, so the gripper and the code that drives it are under one
    licence rather than two stories.
2026-08-31 Rename basebottom.stl to Bottom Base.stl
    [Bottom Base.stl, basebottom.stl]
